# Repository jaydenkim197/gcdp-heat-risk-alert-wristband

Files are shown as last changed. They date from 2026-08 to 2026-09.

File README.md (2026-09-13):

# GCDP Heat Risk Alert Wristband

Wearable safety-alert prototype developed for the 2025-2 Global CDP
Thailand-Korea program. The device measures pulse and skin temperature,
acquires GNSS coordinates, and sends an emergency SMS over LTE-M.

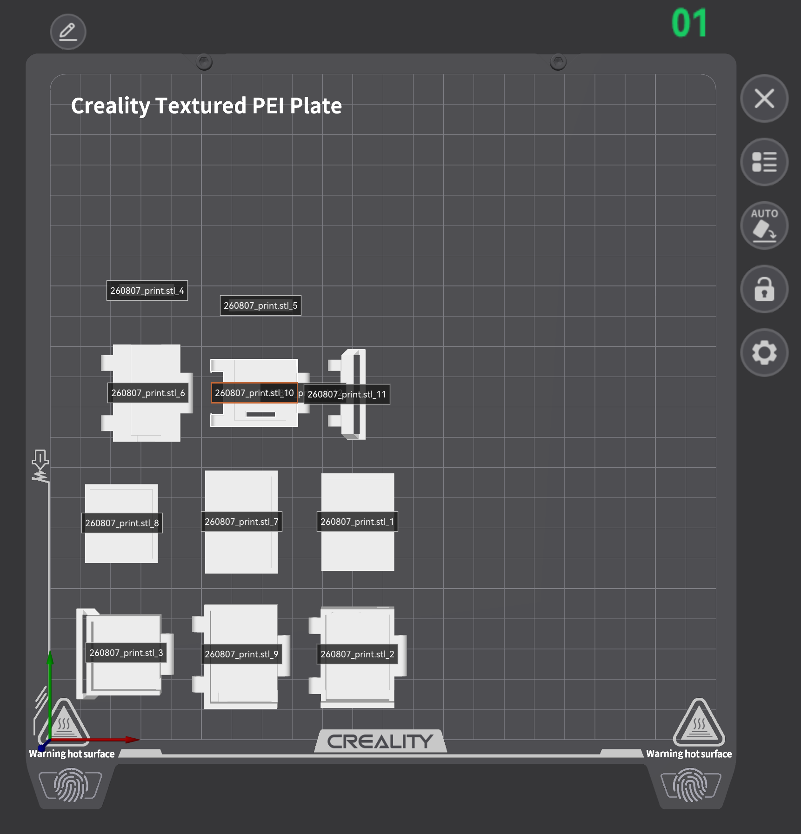
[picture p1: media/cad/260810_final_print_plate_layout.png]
Final modular housing print layout


Latest housing revision prepared for printing on 2026-08-10.

## Prototype Hardware

- ESP32-C3 SuperMini controller
- M5Stack Stamp CatM S003 (SIM7080G) LTE-M/NB-IoT modem
- Beitian BE-220 GNSS module
- MAX30102 pulse/PPG sensor
- TMP117 temperature sensor
- 3 V active buzzer
- 3.7 V 220 mAh Li-Po battery
- Modular 3D-printed hinged housings

## Verified Prototype Functions

- Concurrent MAX30102 and TMP117 acquisition over I2C
- LTE network registration with an activated SKT-network SIM
- GNSS coordinate acquisition
- SMS transmission containing heart rate, temperature, and location
- Battery-powered operation of the integrated prototype
- Standalone buzzer-guided measurement workflow

## ESP32-C3 SuperMini Pin Map

| Function | GPIO |
| --- | ---: |
| I2C SDA (MAX30102/TMP117) | 8 |
| I2C SCL (MAX30102/TMP117) | 9 |
| Stamp CatM RX into ESP | 20 |
| Stamp CatM TX from ESP | 21 |
| BE-220 RX into ESP | 6 |
| BE-220 TX from ESP | 7 |
| Active buzzer | 10 |
| Test trigger | 4 |
| Battery-test input | 5 |

UART labels above are from the ESP32 perspective. Cross the physical UART
connections: module TX to ESP RX, and module RX to ESP TX. All modules must
share ground.

## Repository Layout

- `firmware/`: PlatformIO firmware and captured sensor/UART evidence
- `hardware/pcb/`: Altium schematic and PCB design history
- `hardware/enclosure/`: Fusion export, STEP/STL files, generators, and fit notes
- `docs/`: dated bring-up, integration, power, and module-selection records
- `media/cad/`: selected enclosure renders for quick review
- `evidence/`: dated hardware, 3D-printing, demo, screenshot, and 3D-scan records

For a chronological review of the engineering work, start with
[`evidence/README.md`](evidence/README.md), then read the dated logs in
[`docs/`](docs/). The repository intentionally excludes personal information,
administrative records, raw purchase documents, and generated build caches.

The redacted first-purchase request and supporting quotations are available at
[`docs/260812_GCDP_team5_procurement_request_public.pdf`](docs/260812_GCDP_team5_procurement_request_public.pdf).

Third-party datasheets, downloaded CAD models, raw presentation media,
original procurement files, personal identifiers, and generated build caches
are not tracked in this repository.

## Build and Upload

Open `firmware/` as a PlatformIO project, then run:

```powershell
pio run -e esp32c3_supermini
pio run -e esp32c3_supermini -t upload
pio device monitor -b 115200
```

Before field use, replace the placeholder `STANDALONE_ALERT_NUMBER` in
`firmware/include/pins.h` with the intended recipient number.

## Status

This repository documents a functional presentation prototype. It is not a
certified medical device, and measured values must not be used for diagnosis
or treatment decisions.

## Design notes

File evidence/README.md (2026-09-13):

# Development Evidence

This directory preserves the project evidence that complements the dated
engineering logs in [`../docs/`](../docs/).

## Contents

- `hardware-experiments/`: bench setup photos, early sensor/LTE experiments,
  and enclosure-reference images.
- `3d-printing/`: print-quality evidence, printer and filament settings, and
  the leveling-test STL used during prototype fabrication.
- `demo/`: final outdoor prototype demonstration video.
- `process-screenshots/`: chronological screenshots from the CAD, slicing, and
  prototype assembly process, plus date-level contact sheets.
- `3d-scan/`: final prototype 3D scan for geometry review.

## Related Engineering Logs

- `../docs/260708_hardware_bringup_log.md`: MCU and I2C sensor bring-up.
- `../docs/260709_lte_sms_integrated_firmware_log.md`: LTE, GNSS, SMS, and
  power/UART recovery tests.
- `../docs/260713_battery_standalone_alert_test_log.md`: battery-powered
  standalone alert-flow test.
- `../docs/260731_stamp_catm_bringup_diagnostic.md`: Stamp CatM diagnostic
  measurements and UART validation.
- `../docs/260801_BE-220_bringup_and_fix_log.md`: external GNSS baud-rate
  diagnosis and outdoor-fix validation.

## Scope Note

The artifacts document a functional educational prototype, not a certified
medical device. Third-party datasheets, downloaded reference models, purchase
records, and personal identifiers are intentionally excluded from this public
repository.

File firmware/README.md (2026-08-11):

# Heat Risk Alert Wristband Firmware

Initial PlatformIO firmware workspace for the GCDP Korea prototype.

## Hardware Context

Target device:
- ESP32 main controller
- MAX30102 PPG sensor on I2C
- TMP117 temperature sensor on I2C
- SIM7080G LTE/GNSS module on UART
- Active buzzer on GPIO
- Li-Po battery with TP4056 charging and power regulation

## First Bring-Up Order

1. Build and upload the `esp32dev` environment first.
2. Open the serial monitor at `115200`.
3. Confirm the buzzer chirps once on boot.
4. Confirm I2C scan sees:
   - `0x48` for TMP117
   - `0x57` for MAX30102
5. Confirm the LTE module responds to `AT`.
6. Only after these pass, move to SMS/GPS and state-machine integration.

## Common Commands

From this directory:

```powershell
$pio = "$env:APPDATA\Python\Python311\Scripts\pio.exe"
& $pio run -e esp32dev
& $pio run -e esp32dev -t upload
& $pio device monitor -b 115200
```

Other configured environments:

```powershell
& $pio run -e xiao_esp32c3
& $pio run -e esp32c3_supermini
```

## Default Pin Map

ESP32 DevKitC:

| Function | GPIO |
| --- | ---: |
| I2C SDA | 21 |
| I2C SCL | 22 |
| LTE RX | 16 |
| LTE TX | 17 |
| Buzzer | 25 |

Seeed XIAO ESP32-C3:

| Function | GPIO |
| --- | ---: |
| I2C SDA | 6 |
| I2C SCL | 7 |
| LTE RX | 20 |
| LTE TX | 21 |
| Buzzer | 10 |

ESP32-C3 SuperMini defaults are provisional. Verify against the exact board pinout before wiring.

## Notes

- LTE modules can draw short current spikes above 1 A. Use a stable supply and place bulk capacitance close to the LTE module power input.
- Keep ESP32 and SIM7080G UART grounds common.
- For SIM7080G UART, connect ESP32 TX to module RX and ESP32 RX to module TX.
- The first firmware is intentionally a bring-up sketch, not the final emergency algorithm.

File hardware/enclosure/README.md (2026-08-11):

# GCDP Wristband Case Modeling

Updated: 2026-07-25

Purpose: Fusion workspace for the wearable prototype case/blockout.

## Current Modeling Goal

Create a practical blockout first, not a polished final enclosure.

The prototype will likely be:

- wired modules
- fixed inside a TPU/printed holder
- covered or enclosed enough for wearable presentation
- supported by a presentation-only PCB design image later

## Folder Map

- `fusion`: Fusion source/exported archive files.
- `exports`: STL/STEP/3MF outputs.
- `references`: reference images imported into Fusion or used for modeling.
- `measurements`: measurement tables and photos.
- `renders`: screenshots/renders for reports and presentation.

## Fixed Modules

- ESP32-C3 SuperMini
- M5Stack Stamp CatM S003
- Beitian BE-220 GPS/GNSS
- TMP117 breakout
- MAX30102 breakout
- 3 V active buzzer
- TW-602035 3.7 V 380 mAh Li-Po battery

## Blockout Priority

1. Skin-facing sensor region: MAX30102 optical window and TMP117 contact zone.
2. Top/outward GPS region: BE-220 patch antenna faces outward/upward.
3. LTE region: Stamp CatM and LTE antenna kept away from GPS patch and skin side where possible.
4. Battery protection: avoid sharp compression and provide retention.
5. Debug access: ESP32-C3 USB-C remains reachable.
6. Wire strain relief: every module wire exit needs room.

## First Fusion Components

Create one component per object:

- `WRIST_REFERENCE`
- `CASE_BASE`
- `CASE_LID`
- `ESP32_C3_SUPERMINI_BLOCK`
- `STAMP_CATM_BLOCK`
- `BE220_GPS_BLOCK`
- `BATTERY_BLOCK`
- `MAX30102_BLOCK`
- `TMP117_BLOCK`
- `BUZZER_BLOCK`
- `BUTTON_BLOCK`
- `WIRE_CHANNELS`

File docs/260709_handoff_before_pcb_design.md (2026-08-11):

# 회로 설계 인수인계서

Date: 2026-07-09

Project: GCDP Heat Risk Alert Wristband

Purpose: 회로 설계 채팅으로 넘어가기 전, 지금까지 직접 실험한 사실, 검증 결과, 판단 근거, 확정 결정, 미해결 리스크를 끊기지 않게 전달한다.

## 0. 최종 요약

1차 PCB는 완제품형 칩 통합 PCB가 아니라, 검증된 모듈들을 얹는 carrier board 성격으로 진행한다.

최종 결정:

```text
MCU: ESP32-C3 SuperMini 모듈을 1차 PCB에 그대로 얹는다.
MCU 칩 단위 통합: 1차 PCB에서는 하지 않는다.
GPS/GNSS: 반드시 넣는다.
통신 모듈: 1차 PCB에 통합한다. 기존 대형 devkit은 최종 형상에 부적합하므로 기능 검증용으로만 본다.
배터리: Li-Po 사용.
충전회로: 1차 PCB에는 넣지 않는다.
```

현재까지 보드 기반 기능 검증은 1차 완료로 본다. 남은 핵심 작업은 기능 검증이 아니라 회로 설계 결정이다.

가장 중요한 설계 쟁점:

```text
1. GNSS 포함 통신 모듈 선정
2. SIM7080G 전원 레일 설계
3. Li-Po에서 MCU와 통신 모듈에 어떤 전압을 공급할지 결정
4. SIM7080G PWRKEY/PWRK 회로를 devkit 기준이 아니라 최종 모듈 reference circuit 기준으로 설계
5. MAX30102/TMP117의 실제 착용 구조 반영
```

## 1. 작업 공간 정책

작업 공간 정책은 다음과 같이 확정했다.

```text
N: 드라이브 / NAVER MYBOX cloud
-> 문서, 로그, 설계 메모 보관

C:\Users\sukhe\Desktop\GCDP_codex_temp
-> 임시 개발, PlatformIO build, firmware, capture, 기타 실험 작업
```

활성 펌웨어 작업 경로:

```text
C:\Users\sukhe\Desktop\GCDP_codex_temp\firmware
```

문서/로그 경로:

```text
N:\Own\01_YU\프로젝트 및 활동\2025-2_GCDP(Thailand-Korea)\GCDP_하계(Korea)\project
```

기존에 N 드라이브 쪽에 생겼던 `project\firmware`는 cloud sync와 build/cache 문제를 피하기 위해 삭제했다. 프로젝트 완료 전까지 N 드라이브에는 문서/기록만 둔다.

## 2. 기존 문서와 로그

기존 로그:

```text
N:\Own\01_YU\프로젝트 및 활동\2025-2_GCDP(Thailand-Korea)\GCDP_하계(Korea)\project\logs\2026-07-08_hardware_bringup_log.md
N:\Own\01_YU\프로젝트 및 활동\2025-2_GCDP(Thailand-Korea)\GCDP_하계(Korea)\project\logs\2026-07-09_lte_sms_integrated_firmware_log.md
```

회로 설계 전 메모:

```text
N:\Own\01_YU\프로젝트 및 활동\2025-2_GCDP(Thailand-Korea)\GCDP_하계(Korea)\project\design\pre_pcb_circuit_notes.md
```

본 인수인계서:

```text
N:\Own\01_YU\프로젝트 및 활동\2025-2_GCDP(Thailand-Korea)\GCDP_하계(Korea)\project\design\handoff_before_pcb_design_2026-07-09.md
```

## 3. 개발 환경

PlatformIO 기반으로 진행했다.

설치/사용 확인:

```text
PlatformIO Core
VS Code PlatformIO IDE extension
VS Code C/C++ extension
Espressif32 PlatformIO platform
ESP32 / ESP32-C3 toolchains
```

PlatformIO 환경:

```text
esp32dev
xiao_esp32c3
esp32c3_supermini
```

현재 `platformio.ini`에는 다음 env가 존재한다.

```ini
[env:xiao_esp32c3]
board = seeed_xiao_esp32c3
build_flags =
  -D I2C_SDA_PIN=6
  -D I2C_SCL_PIN=7
  -D LTE_RX_PIN=20
  -D LTE_TX_PIN=21
  -D BUZZER_PIN=10
  -D LTE_PWRK_PIN=5

[env:esp32c3_supermini]
board = esp32-c3-devkitm-1
build_flags =
  -D I2C_SDA_PIN=8
  -D I2C_SCL_PIN=9
  -D LTE_RX_PIN=20
  -D LTE_TX_PIN=21
  -D BUZZER_PIN=10
  -D LTE_PWRK_PIN=5
```

주의:

- 대화 중 XIAO ESP32-C3와 ESP32-C3 SuperMini 비교가 있었다.
- 최종 1차 PCB 결정은 `ESP32-C3 SuperMini 모듈 탑재`이다.
- 펌웨어에는 XIAO와 SuperMini env가 둘 다 들어 있다.
- 회로 설계 채팅에서는 SuperMini 실제 핀맵 기준으로 다시 고정해야 한다.

## 4. MCU 관련 판단

### 4.1 MCU 칩 단위 통합을 하지 않는 이유

1차 PCB에서 MCU를 ESP32-C3 칩 단위로 직접 넣지 않기로 결정했다.

판단 근거:

- ESP32-C3 칩 단위 설계는 USB 회로, EN/BOOT 회로, 3.3 V regulator, crystal/flash/antenna/RF layout, 업로드/디버깅 회로까지 고려해야 한다.
- RF/안테나 layout과 인증/간섭 이슈가 커진다.
- 현재 프로젝트 단계에서는 기능 검증과 1차 착용형 prototype이 우선이다.
- 일정과 디버깅 난이도를 고려하면 MCU 모듈을 carrier PCB에 얹는 것이 현실적이다.

결정:

```text
1차 PCB: ESP32-C3 SuperMini 모듈을 그대로 얹는다.
2차 이후: 필요하면 ESP32-C3 module/chip integration 검토.
```

### 4.2 SuperMini vs XIAO 판단

XIAO ESP32-C3로 바꾸는 데 펌웨어 시간은 크지 않다. 같은 ESP32-C3 계열이고 PlatformIO env도 이미 있다.

하지만 최종 판단:

```text
지금은 SuperMini 유지.
```

판단 근거:

- 현재 주요 병목은 MCU가 아니라 통신 모듈, GPS/GNSS, 전원부다.
- SuperMini는 작고 1차 PCB 크기 감각에 더 가깝다.
- 이미 ESP32-C3 계열에서 센서/부저/LTE 통신 검증이 진행되었다.
- XIAO로 바꾸면 큰 기능 이득보다 핀맵/배선 재확인 비용이 생긴다.

## 5. 센서 검증 결과

### 5.1 TMP117 온도 센서

사용 핀:

```text
VIN
GND
SCL
SDA
INT
ADDR
```

실제 사용:

```text
VIN -> 3V3
GND -> GND
SDA -> I2C SDA
SCL -> I2C SCL
INT -> 미사용
ADDR -> 미사용
```

I2C address:

```text
0x48
```

검증 결과:

- I2C scan에서 `0x48` 감지.
- 온도 읽기 성공.
- 예시 측정값:

```text
32.84 C
33.01 C
33.12 C
33.21 C
```

통합 firmware에서는 TMP117 값이 비정상 범위를 벗어나면 reject하도록 했다.

현재 적용한 sanity range:

```text
-40 C to 125 C
```

설계 주의:

- 피부온도를 의미 있게 보려면 회로보다 기구적 열접촉 구조가 중요하다.
- PCB 위에만 올리면 주변 온도/보드 열 영향을 받을 수 있다.
- 최종 착용 구조에서 TMP117 위치를 피부 쪽에 가깝게 배치해야 한다.

### 5.2 MAX30102 심박/착용 감지 센서

사용 핀 라벨:

```text
GND
D
IRO
INT
VIN
SDA
SCL
GND
```

실제 사용:

```text
VIN -> 3V3
GND -> GND
SDA -> I2C SDA
SCL -> I2C SCL
INT/IRO/D -> 미사용
```

I2C address:

```text
0x57
```

Part ID:

```text
0x15
```

검증 결과:

- I2C scan에서 `0x57` 감지.
- RED/IR raw data 읽기 성공.
- 손가락 올린 상태에서 RED/IR 값 증가 확인.
- 예시 값:

```text
red = 104552
ir  = 130099
```

연속 sampling 예시:

```text
Sample rate: about 49.98 Hz
RED range: 107248 to 107786
IR range: 133719 to 134472
```

초기 BPM 추정:

```text
Mean BPM: 115.2
Median BPM: 115.4
```

해석:

- BPM 추정은 waveform 검증용 crude peak detector였다.
- 최종 심박 알고리즘으로 확정한 것이 아니다.
- 현재 중요한 검증은 optical sensor가 살아 있고 RED/IR waveform이 나온다는 점이다.

착용 감지:

```text
wear on threshold  = 80000
wear off threshold = 60000
confirmation count = 3
```

사용자 확인:

- 손가락/접촉 감지 시 부저 반응.
- delay는 약 1~2초 내외로 느껴졌고 현재 prototype 단계에서는 만족.

설계 주의:

- MAX30102는 회로보다 물리 배치가 중요하다.
- 피부 밀착, 차광, 압력, 센서 창 높이, 주변광 차단을 고려해야 한다.
- PCB에 고정할지, 별도 작은 sensor board로 빼서 피부 접촉부에 둘지 설계 단계에서 결정해야 한다.

### 5.3 TMP117 + MAX30102 동시 I2C 검증

두 센서는 같은 I2C bus에서 동시에 동작했다.

동시 scan 결과:

```text
0x48 TMP117
0x57 MAX30102
```

결론:

```text
TMP117과 MAX30102는 하나의 I2C bus에 같이 연결 가능.
```

회로 설계 주의:

- pull-up 저항 값을 최종 PCB에서 정해야 한다.
- breakout module에 이미 pull-up이 있는 경우 prototype에서는 중복 pull-up이 있을 수 있다.
- 1차 PCB에서 센서를 직접 실장한다면 SDA/SCL에 3.3 V pull-up을 명확히 넣어야 한다.

## 6. 부저 검증 결과

부저 연결:

```text
ESP32-C3 GPIO10 -> buzzer signal
GND -> GND
```

검증 결과:

- GPIO10으로 부저 ON/OFF 확인.
- 착용 감지와 연동해 접촉 시 부저 ON, 제거 시 OFF 테스트 완료.
- 사용자 체감 delay는 prototype 단계에서 만족.

회로 설계 주의:

- active buzzer가 저전류이면 GPIO 직접 구동 가능할 수 있다.
- 부저 전류가 GPIO safe limit을 넘으면 transistor driver를 넣어야 한다.
- wearable 용도이므로 소리 크기/소비전류/사용자 불편감을 같이 고려해야 한다.

## 7. 통신 모듈 실험 결과

### 7.1 작은 SIM7080G 6핀 모듈

핀 라벨:

```text
5V
3V3
GND
Rf
Tx
Rx
```

실험:

- 5V, GND, TX/RX를 ESP32-C3 UART에 연결.
- TX/RX direction 바꿔봄.
- 여러 baud scan.

결과:

```text
LED는 켜졌으나 AT 응답 없음.
```

가능 원인:

- 별도 power key 필요.
- UART가 비활성.
- 전원 조건 문제.
- 보드 내부 동작 조건 불명.

결론:

```text
해당 작은 6핀 모듈은 bring-up 실패. 최종 설계 근거로 사용하지 않는다.
```

### 7.2 SIM7080G developer kit

핀 라벨:

```text
DTR
GND
VDD
PWRK
UTX
URX
GND
```

추가 구성:

- micro USB connector
- 4-pin connector
- 3개 antenna connector

PCB marking:

```text
CAT-1-A76-80X
NB-SIM-7080
SIM-800/868
```

초기 USB test:

- micro USB 연결 시 LED는 켜졌지만 Windows COM port는 새로 잡히지 않았다.
- cable이 power-only일 가능성 또는 USB-UART 미노출 가능성이 있었다.

ESP32-C3 UART 경유 test:

동작한 UART:

```text
SIM7080G DevKit UTX -> ESP32-C3 GPIO20 or GPIO21 실험 중 최종 firmware는 LTE_RX_PIN=20 사용
SIM7080G DevKit URX -> ESP32-C3 GPIO21 or GPIO20 실험 중 최종 firmware는 LTE_TX_PIN=21 사용
GND common
baud = 115200
```

주의:

- 초기 로그에는 배선 방향을 바꿔가며 찾은 흔적이 있다.
- 최종 통합 firmware 기준은 `LTE_RX_PIN=20`, `LTE_TX_PIN=21`.
- 회로 설계 시에는 최종 채택 통신 모듈 datasheet의 TX/RX naming 기준으로 다시 교차 연결해야 한다.

AT 성공:

```text
AT -> OK
ATI -> R1951.07 / OK
AT+CPIN? -> +CPIN: READY
```

## 8. SIM / SKT / SMS 검증

SIM:

- 물리 SIM을 SKT망으로 개통 후 사용.
- SIM 전화번호 및 수신 테스트 전화번호는 대화에 존재하지만 문서에는 개인정보 보호를 위해 그대로 적지 않는다.

SKT network:

성공 PLMN:

```text
45005
```

실패한 PLMN:

```text
45012 -> no network service
```

안테나 전:

```text
AT+CSQ -> 99,99
AT+CEREG? -> 0,2
```

안테나 후:

```text
AT+CSQ -> 23 to 26,99
AT+CEREG? -> registered
AT+COPS? -> 45005 or SKTelecom
AT+CGATT? -> 1
```

Cat-M mode:

```text
AT+CMNB=1
AT+CNMP? -> +CNMP: 38
AT+CBAND? -> ALL_MODE
```

SMS:

실제 SMS 전송 성공.

테스트 메시지:

```text
GCDP SIM7080G SMS TEST
```

사용자 확인:

```text
문자 수신 성공.
```

중요 안전 이슈:

- 초기 test firmware에서 one-shot flag가 RAM에만 있어서 reset/re-upload 후 같은 SMS가 다시 발송되었다.
- 사용자가 SMS 500건 한도를 우려했다.
- 이후 automatic SMS는 모두 막았다.

현재 정책:

```text
SMS는 수동 serial command로만 전송.
부팅, reset, LTE registration, state change만으로는 SMS 전송 금지.
```

현재 SMS 명령:

```text
SMS <number> <message>
```

회로 설계와 직접 관련된 결론:

- SIM7080G 계열로 SKT망 registration과 SMS 송신이 실제로 가능함을 확인했다.
- LTE antenna는 필수다.
- 통신 모듈 전원 안정성이 매우 중요하다.

## 9. GNSS/GPS 검증

GPS/GNSS는 프로젝트 최종 요구사항으로 확정했다.

SIM7080G developer kit에서 GNSS command path는 검증되었다.

추가한 firmware command:

```text
GNSS
GNSSOFF
```

관측 sequence:

```text
AT+CGNSPWR=1
OK
AT+CGNSINF
+CGNSINF: 1,,,36.050000,127.330003,-19.819,,,1,,0.1,0.1,0.1,,,,191841.8,6000.0
OK
[gnss] coordinate acquired
```

GNSS off:

```text
AT+CGNSPWR=0
OK
```

해석:

- `+CGNSINF: 1,1` 형태가 아니어도 latitude/longitude field가 유효하면 coordinate acquired로 처리하도록 firmware 수정했다.
- 실내/창가/안테나 조건에 따라 GNSS fix reliability는 추가 확인 필요.
- 최종 PCB에는 LTE antenna와 GNSS antenna를 별도로 고려해야 한다.

중요 부품 판단:

### M5Stack U137 CatM+GNSS Unit

특징:

- SIM7080G 기반.
- Cat-M/NB-IoT + GNSS 지원.
- LTE/GNSS dual SMA antenna.
- MicroSIM.
- 외부 DC 9-24 V 또는 HY2.0 5 V.
- UART 3.3 V TTL.
- GNSS 지원.
- 크기 약 `62 x 40 x 18.4 mm`.

판단:

- 기능적으로는 통신 + GNSS가 모두 들어 있어 prototype 검증에 유리.
- 하지만 wristband 최종/1차 PCB 관점에서는 크다.

### M5Stamp CAT-M Module S003

특징:

- SIM7080G 기반.
- Cat-M/NB-IoT 지원.
- UART 115200 8N1.
- MicroSIM.
- IPEX LTE antenna.
- 5 V 입력.
- 제품 크기 약 `30.1 x 20.1 x 5.5 mm`.
- GNSS 없음.

판단:

- 작고 1차 PCB에 올리기 좋다.
- 그러나 GPS/GNSS가 없다.
- 최종 요구사항이 GPS 필수이므로 S003 단독은 부적합.

최종 GPS 관련 결정:

```text
GPS/GNSS는 반드시 넣는다.
S003 단독 사용은 안 된다.
통신 모듈은 PCB에 통합하되, GNSS 지원 모듈이거나 별도 GNSS 모듈을 추가해야 한다.
```

회로 설계 채팅에서 가장 먼저 정해야 할 점:

```text
1. SIM7080G 기반 GNSS 지원 모듈을 PCB에 올릴 것인가?
2. 아니면 S003 같은 작은 Cat-M module + 별도 GNSS module 조합으로 갈 것인가?
```

현재 판단 우선순위:

- 크기만 보면 S003이 매력적.
- 하지만 GPS 필수이므로 S003 단독은 탈락.
- 통신+GNSS 통합 모듈을 찾는 것이 회로 단순성 측면에서 유리하다.
- 크기를 더 줄이려면 Cat-M module과 GNSS module을 분리해야 한다.

## 10. PWRK/PWRKEY 전원 제어 실험

SIM7080G developer kit에서 PWRK 관련 실험을 했다.

초기 관찰:

- PWRK를 GND에 1~2초 연결했다가 떼면 green LED가 깜빡이며 살아난 적이 있다.
- 이후 firmware에서 `MODEMPWR` command를 추가해 ESP32-C3 GPIO5로 PWRK를 LOW pulse하도록 했다.

추가 firmware command:

```text
MODEMPWR [ms]
MODEMOFF
PWRKHIGH [ms]
LTEPROBE
```

`MODEMOFF`:

```text
AT+CPOWD=1
```

결과:

- `AT+CPOWD=1`로 modem power-down은 확인했다.
- power-down 후 AT no response 상태 확인.
- `MODEMPWR` LOW pulse로는 관찰 시간 내 modem이 확실히 다시 살아나는 것을 확인하지 못했다.
- `PWRKHIGH 3000`은 modem이 켜져 있을 때 `NORMAL POWER DOWN`을 유발했다.
- 이후 green LED가 깜빡이는 상태에서는 실제로 modem이 살아 있었고, re-upload/reset 및 UART probe 후 AT 통신이 복구되었다.

중요 해석:

- developer kit의 PWRK 핀은 단순한 active-low button이라고 단정하면 안 된다.
- HIGH pulse가 power-down을 유발하는 상황도 관찰되었다.
- external micro-USB power 또는 보조배터리 전원 공급 후 modem 안정성이 좋아졌다.
- no response 상태가 항상 modem death를 의미하지는 않았다. reset/timing/UART synchronization issue일 수 있다.
- 최종 PCB에서 devkit의 PWRK behavior를 그대로 복사하면 안 된다.

최종 설계 지침:

```text
PWRKEY/PWRK는 최종 선택한 SIM7080G module datasheet/reference circuit 기준으로 설계한다.
developer kit behavior는 참고 기록으로만 본다.
```

예상 회로 원칙:

- MCU GPIO가 PWRKEY를 직접 push-pull로 강하게 drive하지 않도록 한다.
- 일반적으로 open-drain/open-collector style low-side control 또는 reference circuit 권장 방식을 따른다.
- power-on/off timing은 module datasheet timing을 따른다.

## 11. 전원 관련 관찰과 최종 결정

관찰:

- SIM7080G developer kit는 전원 조건에 민감했다.
- antenna 연결 전에는 신호가 사실상 없었다.
- 외부 micro-USB/보조배터리 전원 공급 후 modem 안정성이 좋아졌다.
- 통신 모듈은 MCU 3.3 V에서 직접 공급하면 안 된다.
- LTE attach/SMS/GNSS 시 전류 spike를 고려해야 한다.

최종 결정:

```text
1차 PCB 전원: Li-Po 사용.
1차 PCB 충전회로: 넣지 않는다.
```

이 결정의 의미:

- PCB에 charging IC, USB charging path, power-path management를 넣지 않는다.
- Li-Po는 외부 충전 또는 분리 충전을 전제로 해야 한다.
- 단, 안전을 위해 battery protection이 내장된 Li-Po pack을 쓰는지 확인해야 한다.
- PCB에는 최소한 reverse/overcurrent/전원 switch/fuse/protection 필요 여부를 회로 설계에서 판단해야 한다.

필수 설계 과제:

```text
Li-Po nominal 3.7 V, full 4.2 V, cutoff 약 3.0 V대
ESP32-C3 SuperMini 입력 요구 전압
통신 모듈 입력 요구 전압
SIM7080G peak current
5 V boost converter 필요 여부
3.3 V regulator 필요 여부
bulk capacitor 용량과 배치
```

전원 관련 강한 권고:

- SIM7080G 전원 rail 근처에 bulk capacitor를 둔다.
- LTE module power trace는 짧고 넓게 잡는다.
- MCU와 sensor 3.3 V rail이 modem current spike에 흔들리지 않게 분리/필터링을 고려한다.
- 1차 PCB라도 power test point를 반드시 둔다.

## 12. 현재 통합 펌웨어 상태

파일:

```text
C:\Users\sukhe\Desktop\GCDP_codex_temp\firmware\src\main.cpp
C:\Users\sukhe\Desktop\GCDP_codex_temp\firmware\platformio.ini
C:\Users\sukhe\Desktop\GCDP_codex_temp\firmware\include\pins.h
```

구현된 state:

```text
BOOT
NOT_WORN
NORMAL
SUSPECT
ALARM
EMERGENCY_READY
ERROR
```

상태 의미:

```text
BOOT -> 초기화
NOT_WORN -> 착용/접촉 없음
NORMAL -> 착용 감지, 위험 조건 없음
SUSPECT -> 위험 의심 조건 시작
ALARM -> 위험 조건 지속
EMERGENCY_READY -> 알림 전송 준비 상태
ERROR -> sensor failure 지속
```

현재 주요 parameter:

```text
SENSOR_SAMPLE_MS = 100
TEMP_SAMPLE_MS = 1000
STATUS_PRINT_MS = 1000
LTE_CHECK_MS = 60000
SUSPECT_CONFIRM_MS = 10000
ALARM_COUNTDOWN_MS = 30000
WEAR_ON_IR_THRESHOLD = 80000
WEAR_OFF_IR_THRESHOLD = 60000
WEAR_CONFIRM_COUNT = 3
TEMP_SUSPECT_C = 38.0
```

현재 serial commands:

```text
HELP
STATUS
LTE
LTEPROBE
GNSS
GNSSOFF
MODEMPWR [ms]
PWRKHIGH [ms]
MODEMOFF
ALARM
CANCEL
SMS <number> <message>
```

SMS safety:

```text
Automatic SMS disabled.
Manual command only.
```

센서 안정성 patch:

- TMP117 transient fail이 몇 번 발생해도 즉시 ERROR로 가지 않도록 했다.
- MAX30102 transient fail도 즉시 ERROR로 가지 않도록 했다.
- 짧은 I2C failure에는 last valid reading을 유지한다.
- 지속 failure일 때만 ERROR.

## 13. 1차 PCB에 반영할 기능 블록

1차 PCB block:

```text
Li-Po battery input
Power switch / protection / regulation
ESP32-C3 SuperMini module seat
GNSS-capable Cat-M/NB-IoT communication module or Cat-M + separate GNSS
MicroSIM holder if module does not include one
LTE antenna connector
GNSS antenna connector
TMP117 temperature sensor
MAX30102 optical sensor
Buzzer driver/output
Debug/programming access
Test points
```

1차 PCB에서 하지 않는 것:

```text
ESP32-C3 chip-level integration
charging circuit
fully optimized final wearable miniaturization
RF tuning beyond reasonable module reference layout
```

## 14. 회로 설계에 넘길 확정 결정

확정:

```text
GPS/GNSS 기능은 반드시 포함한다.
1차 PCB에서 MCU는 ESP32-C3 SuperMini 모듈을 그대로 얹는다.
1차 PCB에서 MCU 칩 단위 통합은 하지 않는다.
통신 모듈은 PCB에 통합한다.
기존 SIM7080G developer kit는 기능 검증용이며 최종 1차 PCB 탑재 대상이 아니다.
Li-Po battery를 사용한다.
1차 PCB에는 충전회로를 넣지 않는다.
SMS는 자동 발송하지 않는다. 자동 emergency workflow는 별도 구현 전까지 막아둔다.
TMP117과 MAX30102는 같은 I2C bus에 연결 가능하다.
부저는 GPIO로 제어 가능함을 확인했다.
LTE/SMS/GNSS는 SIM7080G 계열에서 실제 동작 확인했다.
```

미확정:

```text
최종 GNSS 포함 통신 모듈 part number
Cat-M+GNSS 통합 모듈 vs Cat-M 모듈 + 별도 GNSS 모듈
SIM holder를 module 내장으로 쓸지 PCB에 둘지
LTE antenna connector type
GNSS antenna connector type
Li-Po 전압을 어떤 rail로 변환할지
5 V boost 필요 여부
3.3 V regulator 구성
PWRKEY/PWRK 회로
MAX30102/TMP117 물리 배치
부저 driver 필요 여부
배터리 protection/fuse/switch 방식
```

## 15. 회로 설계 시작 순서 권장

다음 채팅에서 회로 설계를 시작할 때는 이 순서가 좋다.

```text
1. 최종 통신/GNSS 모듈 선정
2. 해당 module datasheet/reference circuit 확보
3. module 전원 요구사항 확인
4. Li-Po -> required rails power tree 작성
5. ESP32-C3 SuperMini carrier pin map 확정
6. I2C sensor bus 확정
7. LTE/GNSS antenna connector and placement 결정
8. SIM holder/module 내장 여부 결정
9. buzzer driver 여부 결정
10. test point/debug connector 추가
11. schematic 작성
12. ERC/DFM 검토
```

가장 먼저 볼 것:

```text
GPS 필수이므로 S003 단독은 탈락.
통신+GNSS를 통합한 작은 module을 찾거나, S003급 Cat-M module + small GNSS module 조합으로 간다.
```

## 16. 다음 채팅에 반드시 전달해야 하는 경고

1. `PWRK`는 devkit에서 이상하게 동작했다. 최종 PCB는 devkit wiring을 베끼지 말고 최종 module datasheet를 따라야 한다.

2. `S003 M5Stamp CAT-M`은 작지만 GNSS가 없다. GPS 필수 조건과 충돌한다.

3. `U137 CatM+GNSS Unit`은 GNSS가 있지만 크다. 1차 PCB에 그대로 쓰기보다는 기능 reference로 보는 편이 낫다.

4. SIM7080G 계열은 전원 안정성이 중요하다. 보조배터리/외부전원 연결 후 안정성이 개선된 경험이 있다.

5. SMS 자동 발송은 조심해야 한다. reset/re-upload로 중복 문자 발송된 경험이 있으므로 rate limit과 persistent sent flag 없이는 자동 SMS를 켜면 안 된다.

6. MAX30102는 회로보다 기구/착용 구조가 성능에 큰 영향을 준다.

7. TMP117도 피부온도 측정 목적이면 기구적 열접촉 설계가 필요하다.

8. N drive에는 firmware/build를 두지 않는다. 문서와 기록만 둔다.

## 17. 현재 판단의 한 문장 버전

```text
센서, 부저, LTE, SMS, GNSS의 기능 검증은 끝났고, 1차 PCB는 ESP32-C3 SuperMini를 얹는 carrier board로 가며, GPS는 필수이므로 GNSS 포함 통신 모듈 또는 별도 GNSS 모듈을 선정한 뒤 Li-Po 기반 전원부와 SIM7080G reference 회로를 중심으로 schematic을 시작해야 한다.
```

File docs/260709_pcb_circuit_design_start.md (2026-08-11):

# GCDP Heat Risk Alert Wristband - 1st PCB Circuit Design Start

Date: 2026-07-09

Scope: 1차 PCB 회로 설계 시작 문서. 인수인계서, 기존 bring-up 로그, pre-PCB 회로 메모를 기준으로 누락 결정사항을 점검하고, 블록 다이어그램, 부품 후보, 전원 구조, ESP32-C3 SuperMini carrier pin map, schematic 작성 순서를 정리한다.

## 1. 설계 기준 요약

확정 기준:

- 1차 PCB는 완제품형 칩 통합 PCB가 아니라 검증된 모듈을 얹는 carrier board로 설계한다.
- MCU는 ESP32-C3 SuperMini 모듈을 그대로 탑재한다.
- MCU 칩 단위 통합은 1차 PCB에서 하지 않는다.
- GPS/GNSS는 반드시 포함한다.
- 통신 모듈은 PCB에 통합한다. 기존 SIM7080G developer kit는 최종 탑재 대상이 아니다.
- Li-Po 배터리를 사용한다.
- 1차 PCB에는 충전회로를 넣지 않는다.
- SMS 자동 발송은 계속 금지한다. 현재 정책은 manual serial command only.

검증 완료 기반:

- TMP117, MAX30102, I2C 동시 동작, buzzer GPIO, SIM7080G UART AT, SKT 등록, SMS 송신, SIM7080G GNSS 좌표 수신 확인 완료.
- 통신 모듈 전원 안정성과 antenna 연결은 1차 PCB 설계 핵심 리스크다.

## 2. 누락된 설계 결정사항 점검

| 항목 | 현재 판단 | 1차 PCB 결정 |
| --- | --- | --- |
| 통신/GNSS 모듈 | SIM7080G 계열에서 실제 SKT/SMS/GNSS 검증됨 | 1차 권장: SIM7080G bare SMT module |
| 통합형 vs 분리형 GNSS | 분리형은 부품/펌웨어/antenna가 늘어남 | 통신+GNSS 통합 모듈 우선 |
| SIM holder | bare SIM7080G는 외부 SIM socket 필요 | PCB에 nano/micro SIM holder 배치 |
| LTE antenna connector | developer kit에서 antenna 없이는 사실상 수신 불가 | u.FL/IPEX 계열 우선, 50 ohm RF + PI matching reserve |
| GNSS antenna connector | GNSS 필수, LTE와 별도 고려 필요 | u.FL/IPEX 계열 우선, active/passive 선택 전원 옵션 reserve |
| Li-Po 전원 rail | SIM7080G VBAT 범위가 Li-Po 직접 연결 가능 범위와 겹침 | Li-Po -> protected/switched VBAT_MODEM 직접 공급안 우선 |
| 3.3 V rail | SuperMini/센서용 안정 rail 필요 | Li-Po -> 3.3 V regulator, modem rail과 분리 |
| 5 V boost | SIM7080G bare module에는 필수 아님 | 기본 미사용. SuperMini 5V pin 사용 여부는 조립 옵션으로만 |
| PWRKEY | devkit 동작 복사 금지 | SIM7080G datasheet 기준, open-drain low-side pull-down |
| UART level | SIM7080G UART는 1.8 V domain | ESP32-C3 3.3 V UART와 level shifter 필요 |
| Buzzer driver | buzzer 전류 미확정 | transistor low-side driver 기본 적용 |
| Sensor placement | 회로보다 기구 영향 큼 | MAX30102/TMP117은 skin-side edge/별도 sensor island 고려 |
| Debug/test | PCB bring-up 필수 | UART, I2C, 3V3, VBAT_MODEM, PWRKEY, STATUS, RF option test points |

## 3. 통신/GNSS 모듈 후보

### 3.1 1차 권장: SIMCom SIM7080G bare SMT module

선정 이유:

- 이미 SIM7080G 계열 developer kit로 SKT 등록, SMS 송신, GNSS 좌표 수신을 확인했다.
- SIMCom 공식 제품 정보 기준 SIM7080G는 CAT-M/NB-IoT SMT 모듈이며 GNSS 옵션을 제공한다.
- 크기는 약 17.6 mm x 15.7 mm x 2.3 mm로 1차 wristband carrier PCB에 현실적인 편이다.
- 공급 전압 범위는 2.7 V to 4.8 V라 1-cell Li-Po 전압 범위와 직접 연결 가능하다.
- hardware design 문서 기준 CAT-M/NB-IoT emission peak current는 0.5 A 수준을 고려해야 한다.

주의:

- SIM7080G UART/GPIO는 1.8 V domain이다. ESP32-C3 3.3 V와 직접 연결하지 말고 level shifter 또는 reference transistor circuit을 넣는다.
- SIM card는 1.8 V SIM만 지원한다고 문서에 명시되어 있으므로 SIM holder/USIM 호환성을 확인한다.
- PWRKEY는 내부 1.8 V pull-up이 있으며, 1초 이상 low pulse로 power-on, 1.2초 이상 low pulse로 power-off한다. 상시 GND short 금지.
- RF_ANT와 GNSS_ANT가 별도 pad로 존재하므로 LTE/GNSS antenna connector를 분리한다.

### 3.2 대안 A: Quectel BG77/BG770A-GL 계열

장점:

- SIM7080G보다 더 작은 초소형 LPWA + GNSS 계열로 wristband 최종형에는 매력적이다.
- LTE Cat M1/NB-IoT와 GNSS 통합 방향성은 프로젝트 요구와 맞다.

리스크:

- 현재 firmware, AT command path, SKT/SMS/GNSS 검증은 SIM7080G 기준이다.
- 1차 PCB에서 모듈을 바꾸면 bring-up 리스크가 커진다.
- SIM/PWRKEY/PON_TRIG/power sequencing이 SIM7080G와 다르므로 reference circuit 재검토가 필요하다.

### 3.3 대안 B: M5Stamp CAT-M S003 + 별도 GNSS

판단:

- S003은 작지만 GNSS가 없어 단독 사용 불가다.
- 별도 GNSS 모듈을 추가하면 antenna, UART/I2C, 전원, firmware integration이 늘어난다.
- 1차 PCB 회로 단순성 관점에서는 권장하지 않는다.

결론:

```text
1차 PCB schematic 초안은 SIM7080G bare SMT module 기준으로 시작한다.
BG77/BG770A 계열은 2차 소형화 후보로 남긴다.
```

## 4. 1차 PCB 블록 다이어그램

```mermaid
flowchart LR
  BAT["Protected 1S Li-Po pack<br/>JST or solder pads"] --> SW["Power switch<br/>fuse / reverse protection option"]
  SW --> VBAT["VBAT_MODEM<br/>2.7-4.8 V high-current rail"]
  SW --> REG33["3.3 V regulator<br/>MCU + sensors"]

  VBAT --> MODEM["SIM7080G SMT module<br/>Cat-M/NB-IoT + GNSS"]
  REG33 --> MCU["ESP32-C3 SuperMini module"]
  REG33 --> TMP["TMP117<br/>skin temperature"]
  REG33 --> MAX["MAX30102<br/>optical / wear detection"]
  REG33 --> BUZDRV["Buzzer driver"]

  MCU -- "I2C GPIO8/9" --> TMP
  MCU -- "I2C GPIO8/9" --> MAX
  MCU -- "UART GPIO20/21 via 3.3V-1.8V level shift" --> MODEM
  MCU -- "GPIO5 open-drain control" --> MODEM
  MCU -- "GPIO10" --> BUZDRV
  BUZDRV --> BUZ["Active buzzer"]

  MODEM --> SIM["1.8 V SIM holder<br/>ESD + 100 nF near socket"]
  MODEM --> LTEANT["LTE u.FL/IPEX<br/>50 ohm + PI matching"]
  MODEM --> GNSSANT["GNSS u.FL/IPEX<br/>active/passive option"]
  MCU --> DBG["Debug/test header<br/>UART/USB pads/I2C/power"]
```

## 5. 전원 구조 초안

### 5.1 권장 power tree

```text
Protected 1S Li-Po pack
  -> main power switch / removable jumper
  -> VBAT_RAW
      -> VBAT_MODEM: SIM7080G VBAT pins, short/wide trace, bulk caps near module
      -> 3V3_REG: ESP32-C3 SuperMini 3V3 pin, TMP117, MAX30102, buzzer logic
```

### 5.2 SIM7080G VBAT rail

설계값:

- Nominal: 3.7 V Li-Po
- Full: 4.2 V
- SIM7080G allowed: 2.7 V to 4.8 V
- Peak design current: at least 0.5 A, margin 포함해서 regulator/protection/trace는 1 A급 이상으로 설계

회로:

- VBAT pins 34/35는 반드시 함께 연결한다.
- VBAT_MODEM trace는 짧고 넓게. 1차 PCB에서는 최소 1 mm 이상, 가능하면 2 mm급 polygon/plane 사용.
- 모듈 VBAT pin 근처에 bulk + MLCC를 배치한다.
- 초기 schematic capacitor reserve:
  - 100 uF low-ESR bulk x 2 or x 3 near SIM7080G VBAT
  - 10 uF
  - 1 uF
  - 100 nF
  - TVS diode near VBAT pins
- 정상 동작 중 VBAT를 강제로 끊는 설계는 피한다. power-off는 AT+CPOWD=1 또는 PWRKEY 절차를 우선한다.

### 5.3 3.3 V rail

용도:

- ESP32-C3 SuperMini 3V3 input
- TMP117
- MAX30102
- buzzer driver input side
- level shifter MCU side

요구:

- modem current spike가 3.3 V rail에 직접 흔들림을 주지 않게 VBAT_MODEM과 decoupling/return path를 분리한다.
- SuperMini의 5V pin으로 공급할지 3V3 pin으로 공급할지는 모듈 상세 회로 확인 후 freeze한다. 1차 schematic에는 3V3 regulated input을 기본으로 잡고, 필요시 5V boost option footprint를 DNP로 남긴다.

### 5.4 배터리/보호

1차 PCB에는 충전회로를 넣지 않는다.

필수 조건:

- protected Li-Po pack 사용을 BOM/조립 지시서에 명시한다.
- PCB 입력단에 power switch 또는 removable jumper를 둔다.
- fuse/polyfuse 또는 0 ohm shunt footprint를 둬 bring-up 시 current measurement 가능하게 한다.
- reverse protection은 connector 실수 가능성이 있으면 ideal diode/load switch 또는 series protection footprint를 둔다.

## 6. ESP32-C3 SuperMini carrier pin map

SuperMini 기준 최종 draft:

| Function | ESP32-C3 SuperMini pin | Net | 비고 |
| --- | --- | --- | --- |
| I2C SDA | GPIO8 | I2C_SDA_3V3 | SuperMini pinout의 SDA. firmware `esp32c3_supermini` env와 일치 |
| I2C SCL | GPIO9 | I2C_SCL_3V3 | SuperMini pinout의 SCL |
| LTE UART RX | GPIO20 | LTE_TXD_TO_MCU_1V8 via level shift | modem TXD -> MCU RX |
| LTE UART TX | GPIO21 | LTE_RXD_FROM_MCU_1V8 via level shift | MCU TX -> modem RXD |
| LTE PWRKEY control | GPIO5 | LTE_PWRKEY_CTL | N-MOS/NPN open-drain low-side |
| Buzzer PWM/ON | GPIO10 | BUZZER_CTL | transistor driver 권장 |
| Optional status input | GPIO4 or GPIO3 | LTE_STATUS_1V8 via level shift | SIM7080G STATUS 읽기 옵션 |
| Optional modem DTR | GPIO2 | LTE_DTR_1V8 via level shift | sleep mode 제어 옵션, 초기 DNP 가능 |
| Boot/USB native | module USB-C | programming/debug | SuperMini 자체 USB-C 유지 |

주의:

- XIAO bring-up 로그의 GPIO6/GPIO7 I2C는 검증 이력으로만 본다. 1차 PCB는 SuperMini 탑재가 확정이므로 GPIO8/GPIO9를 I2C 기본으로 사용한다.
- GPIO20/21은 현재 integrated firmware의 SuperMini env와 일치하게 유지한다.
- modem UART는 1.8 V라 level shifting이 필요하다. devkit UART 핀이 3.3 V tolerant처럼 동작했던 경험을 bare module에 적용하지 않는다.

## 7. 센서 회로 초안

### 7.1 I2C common bus

```text
3V3_REG
  -> 4.7 k pull-up to I2C_SDA_3V3
  -> 4.7 k pull-up to I2C_SCL_3V3
ESP32-C3 GPIO8/GPIO9
  -> TMP117
  -> MAX30102
```

초기값:

- Pull-up: 4.7 k to 3.3 V
- Test point: SDA, SCL, 3V3, GND
- Address:
  - TMP117: 0x48
  - MAX30102: 0x57

### 7.2 TMP117

- VIN -> 3V3_REG
- GND -> GND
- SDA/SCL -> I2C bus
- ADDR -> default 0x48. 필요시 solder jumper option reserve.
- INT -> test pad 또는 MCU spare pin option, 초기 DNP.
- 기구: skin-side thermal contact가 중요하다. LTE/modem/regulator 발열과 분리한다.

### 7.3 MAX30102

- VIN -> 3V3_REG
- GND -> GND
- SDA/SCL -> I2C bus
- INT -> test pad 또는 MCU spare pin option, 초기 DNP 가능.
- 기구: optical window, 차광, 피부 압력, sensor height가 성능을 좌우한다. 1차 PCB에서는 sensor를 board underside 또는 edge island에 배치하는 안을 우선 검토한다.

## 8. SIM7080G 회로 초안

필수 nets:

```text
VBAT_MODEM
GND
PWRKEY
STATUS optional
UART1_TXD / UART1_RXD
SIM_VDD / SIM_DATA / SIM_CLK / SIM_RST / SIM_DET optional
RF_ANT
GNSS_ANT
USB_DP / USB_DM / USB_VBUS test pads optional
BOOT_CFG test pad, keep open for normal boot
VDD_EXT test pad
```

PWRKEY:

- MCU GPIO5 -> gate/base drive -> N-MOS/NPN low-side pull-down.
- PWRKEY external pull-up 없음.
- Power-on pulse: 1.0 s 이상, 12.6 s 미만.
- Power-off pulse: 1.2 s 이상 또는 AT+CPOWD=1.
- PWRKEY를 GND에 영구 short하지 않는다.

UART level shift:

- ESP32-C3 3.3 V UART <-> SIM7080G 1.8 V UART.
- TX/RX 모두 level shifter 적용.
- 초기 회로는 2-channel auto-direction level translator보다 unidirectional UART용 translator 또는 reference BJT circuit을 우선 검토한다.

SIM holder:

- 1.8 V SIM 기준.
- SIM socket은 module 가까이 배치한다.
- SIM_VDD에 100 nF capacitor를 socket 가까이에 둔다.
- SIM_CLK는 짧고 GND guard 우선. branch 금지.
- SIM line ESD diode는 low-capacitance type.

## 9. Antenna / RF 배치 결정

1차 결정:

- LTE antenna connector: u.FL/IPEX.
- GNSS antenna connector: u.FL/IPEX.
- LTE RF_ANT와 GNSS_ANT는 별도 connector와 별도 50 ohm trace.
- 각 RF path에 PI matching network reserve:
  - series 0 ohm default
  - shunt C/L footprints DNP
- RF ESD TVS는 low capacitance 부품 footprint reserve.

배치 원칙:

- RF trace는 짧게, 50 ohm controlled impedance.
- right angle 금지, GND via fence 사용.
- LTE antenna와 GNSS antenna는 가능한 멀리 배치한다.
- SIM7080G hardware design checklist 기준 LTE main antenna와 GNSS antenna decoupling 목표는 30 dB 이상이다.
- GNSS active antenna를 쓸 가능성이 있으므로 GNSS antenna bias supply option footprint를 둔다. passive antenna만 쓸 경우 external LNA 필요성이 생기므로 1차 bring-up은 active GNSS antenna option을 더 현실적으로 본다.

## 10. Buzzer 회로 초안

권장:

```text
GPIO10 -> base/gate resistor -> N-MOS or NPN low-side switch -> active buzzer -> 3V3 or VBAT
```

- Active buzzer 사용.
- buzzer 정격 전류 확인 전까지 GPIO direct drive는 최종 schematic에서 피한다.
- magnetic buzzer라면 flyback diode 또는 적절한 clamp를 고려한다.
- Test point: BUZZER_CTL.

## 11. Debug / test point

필수 test points:

- GND multiple
- VBAT_RAW
- VBAT_MODEM near modem
- 3V3_REG
- I2C_SDA, I2C_SCL
- LTE_TXD_1V8, LTE_RXD_1V8
- MCU_UART_RX/TX 3.3 V side
- PWRKEY
- STATUS
- VDD_EXT
- BOOT_CFG, keep open
- SIM_VDD
- GNSS antenna bias rail if used

Debug connector:

- 1x6 or pads:
  - GND
  - 3V3
  - MCU TX
  - MCU RX
  - I2C SDA
  - I2C SCL
- SuperMini USB-C는 firmware upload/debug용으로 접근 가능해야 한다.

## 12. Schematic 작성 순서

1. Sheet 1: Title / system notes / design constraints
2. Sheet 2: Battery input, switch, protection, current-measure jumper
3. Sheet 3: 3.3 V regulator and decoupling
4. Sheet 4: ESP32-C3 SuperMini carrier footprint and headers
5. Sheet 5: SIM7080G module, VBAT bulk caps, PWRKEY, STATUS, UART level shift
6. Sheet 6: SIM holder and SIM ESD
7. Sheet 7: LTE antenna, GNSS antenna, matching networks, GNSS bias option
8. Sheet 8: TMP117 and MAX30102 I2C sensors
9. Sheet 9: Buzzer driver
10. Sheet 10: Test points and debug connector
11. ERC pass: power flags, level domains, no-connect pins, SIM/RF warnings 확인
12. Pre-layout checklist: power trace width, RF keepout, sensor placement, antenna separation, SuperMini USB access

## 13. Schematic freeze 전 확인 필요

부품/구매 확인:

- SIM7080G bare module 실제 구매처와 exact variant 확인.
- 1.8 V SIM이 현재 SKT physical SIM과 호환되는지 확인.
- u.FL/IPEX connector footprint와 antenna cable/antenna 확보.
- active GNSS antenna를 쓸지 passive GNSS antenna + LNA를 쓸지 결정.
- 3.3 V regulator part number와 peak/load 조건 확인.
- Li-Po pack 보호회로 내장 여부 확인.
- buzzer 정격 전류 확인.

전기 확인:

- SuperMini에 3V3 pin 직접 공급 시 onboard regulator/USB 연결과 충돌이 없는지 확인.
- SIM7080G UART level shifter 회로를 reference design 기준으로 확정.
- PWRKEY pulse 회로를 SPICE까지는 아니어도 logic-level 관점에서 검토.
- LTE attach/SMS/GNSS 중 VBAT_MODEM droop를 측정할 수 있도록 current shunt/test pads 준비.

기구 확인:

- MAX30102 optical window 위치.
- TMP117 thermal contact 위치.
- LTE/GNSS antenna 위치와 wrist 착용 시 인체/배터리/ground 영향.
- SIM holder 접근성.
- Li-Po 배터리 위치와 교체/충전 방식.

## 14. 사용한 외부 reference

- SIMCom SIM7080G official product page: https://www.simcom.com/product/SIM7080G.html
- SIM7080G Hardware Design V1.04 PDF: https://edworks.co.kr/wp-content/uploads/2022/04/SIM7080G_Hardware_Design_V1.04.pdf
- Quectel BG95 Series Hardware Design V1.5 PDF: https://images.quectel.com/python/2023/04/Quectel_BG95_Series_Hardware_Design_V1.5.pdf
- Quectel BG77 Hardware Design V1.3 PDF: https://images.quectel.com/python/2023/04/Quectel_BG77_Hardware_Design_V1.3.pdf
- Quectel BG770A-GL product/spec reference: https://static6.arrow.com/aropdfconversion/57cf8525af9901a4e073efe507a9298412b7cf4a/quectelbg770a-gl.pdf

## 15. 현재 회로 설계 결정 한 줄 버전

```text
1차 PCB는 ESP32-C3 SuperMini + SIM7080G bare SMT module + PCB SIM holder + LTE/GNSS u.FL antenna + Li-Po direct modem rail + separate 3.3 V rail 구조로 schematic 초안을 시작한다.
```

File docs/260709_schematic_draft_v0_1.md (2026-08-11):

# GCDP Heat Risk Alert Wristband - Schematic Draft v0.1

Date: 2026-07-09

Purpose: 최신 실험 로그와 현재 firmware 상태를 반영해 1차 PCB schematic 초안을 sheet별로 확정한다. 이 문서는 KiCad 회로도 작성 전의 회로 설계 기준이다.

## 0. 최신 실험 반영사항

최신 로그에서 확인된 사실:

- 센서 착용 상태에서 `worn=1`, TMP117 온도, MAX30102 RED/IR 값 정상 확인.
- SIM7080G 계열 보드에서 SKTelecom 등록, `CGATT: 1`, `CSQ 24~25` 확인.
- GNSS 좌표 포함 emergency-format SMS 전송 성공.
- `ALERTSMS 01000000000` 형태처럼 전화번호는 하이픈 없이 digits only로 넣어야 `AT+CMGS` prompt가 정상적으로 나온다.
- 하이픈 포함 번호는 `AT+CMGS` 단계에서 `ERROR`가 발생했다.
- GNSS 응답 예:

```text
+CGNSINF: 1,,,36.050000,127.330003,-19.819,,,1,,0.1,0.1,0.1,,,,191841.6,6000.0
```

- SMS 성공 응답:

```text
+CMGS: 8
OK
```

중요 해석:

- 최종 제품 기능 흐름인 sensor + GNSS + SMS는 firmware/모듈 레벨에서 검증됐다.
- 현재 PWRK 실험은 developer kit/CoreBoard 레벨의 PWRK 동작이다. 최종 bare SIM7080G module schematic은 반드시 SIM7080G Hardware Design의 PWRKEY reference를 따른다.
- 현재 최신 빌드 산출물은 `xiao_esp32c3` 기준이지만, 1차 PCB 목표 MCU는 ESP32-C3 SuperMini다. 회로도는 SuperMini pinout 기준으로 작성한다.

## 1. 1차 PCB 설계 목표 재정의

1차 PCB는 완성형 wearable이 아니라 다음을 검증하는 bring-up carrier board다.

```text
1. SIM7080G bare module 직접 실장 성공
2. Li-Po 기반 VBAT 전원에서 LTE/SMS/GNSS 안정 동작
3. ESP32-C3 SuperMini + SIM7080G UART/PWRKEY 제어
4. 기존 TMP117/MAX30102 sensor module 4-wire 연동
5. buzzer 경고 출력
6. RF/SIM/power debug 가능한 test point 확보
```

1차에서 하지 않는 것:

```text
충전회로
USB-C 충전
ESP32-C3 bare chip 설계
MAX30102/TMP117 IC 직접 실장
PCB antenna
eSIM/MFF2 SIM
상용 방수/최종 착용감 최적화
자동 SMS 무제한 활성화
```

## 2. Schematic Sheet 구성

```text
Sheet 1  SYS_NOTES
Sheet 2  BATTERY_POWER
Sheet 3  ESP32C3_SUPERMINI
Sheet 4  SIM7080G_MODEM
Sheet 5  SIM_CARD
Sheet 6  RF_LTE_GNSS
Sheet 7  SENSOR_4WIRE
Sheet 8  BUZZER
Sheet 9  TEST_DEBUG
```

## 3. Sheet 1 - SYS_NOTES

회로도 첫 장에 다음 설계 note를 넣는다.

```text
1st PCB is a bring-up carrier board.
MCU is ESP32-C3 SuperMini module, not bare ESP32-C3.
Modem is bare SIM7080G SMT module, not developer kit/CoreBoard.
No charging circuit on this PCB.
Use protected 1S Li-Po pack only.
SMS automatic sending remains disabled unless persistent rate-limit is implemented.
Phone number for AT+CMGS must be digits only, no hyphen.
```

전압 domain:

```text
VBAT_SYS       1S Li-Po raw battery rail, 3.0~4.2 V practical range
VBAT_MODEM     SIM7080G high-current rail, directly from VBAT_SYS
3V3            ESP32-C3 SuperMini, sensors, buzzer logic
1V8_MODEM      SIM7080G logic domain / VDD_EXT reference, do not load heavily
RF_LTE         50 ohm RF path
RF_GNSS        50 ohm RF path
```

## 4. Sheet 2 - BATTERY_POWER

### 4.1 Battery Input

Connector:

```text
J_BAT: 1.25 mm 2-pin Li-Po connector
Pin 1: VBAT_IN
Pin 2: GND
Battery target: TW-602035 Li-Po 380 mAh, protected pack preferred
```

Protection/minimum debug:

```text
F1: optional polyfuse or 0 ohm current-measure link
D1: optional reverse protection footprint, DNP if battery connector polarity is keyed and controlled
TP_VBAT_IN
TP_GND near battery connector
```

Decision:

- 물리 power switch는 1차에서 제외 가능.
- 단, current measurement를 위해 `0 ohm link` 또는 solder jumper는 반드시 둔다.
- 배터리 커넥터 탈착으로 hard power cycle 가능하게 한다.

### 4.2 Modem VBAT Rail

Net:

```text
VBAT_IN -> F1/current link -> VBAT_SYS -> VBAT_MODEM
```

SIM7080G VBAT decoupling, modem pin 근처:

```text
C_MODEM_BULK1: 100 uF low-ESR SMD, >=6.3 V
C_MODEM_10U1: 10 uF ceramic, >=6.3 V
C_MODEM_1U1: 1 uF ceramic
C_MODEM_100N1: 100 nF ceramic
C_MODEM_BACKUP: large electrolytic/polymer backup footprint, DNP default
  footprint should accept available 470 uF / 1000 uF / 2200 uF leaded capacitor by hand solder if needed
TP_VBAT_MODEM near SIM7080G VBAT pins
```

Layout note:

```text
VBAT_MODEM trace/polygon must be short and wide.
Place bulk capacitors as close as possible to SIM7080G VBAT pins.
Provide many GND vias around modem power capacitors.
```

### 4.3 3.3 V Rail

Regulator:

```text
U_3V3: 3.3 V LDO, >=500 mA, low dropout, not AMS1117
Candidate class: AP2112K-3.3 / ME6211-3.3 500mA / TLV75533 or equivalent
```

Generic schematic:

```text
VBAT_SYS -> U_3V3 VIN
U_3V3 VOUT -> 3V3
U_3V3 GND -> GND
U_3V3 EN -> VBAT_SYS through 100 k or tied to VIN if no EN sequencing needed
C_LDO_IN: 10 uF near VIN
C_LDO_OUT: 10 uF near VOUT
C_3V3_100N: 100 nF near each IC/module load
TP_3V3
```

Caution:

- SuperMini 3V3 pin 직접 공급은 USB 연결 시 역전류 가능성을 실제 보드에서 확인해야 한다.
- 회로에는 `R_SUPERMINI_3V3_LINK = 0 ohm`을 넣어 SuperMini 3V3 rail을 분리 가능하게 한다.

## 5. Sheet 3 - ESP32C3_SUPERMINI

Module:

```text
U_MCU: ESP32-C3 SuperMini module, soldered directly to carrier PCB
```

Power:

```text
3V3 -> R_SUPERMINI_3V3_LINK 0 ohm -> SuperMini 3V3
GND -> SuperMini GND
SuperMini 5V/VIN: NC by default
USB-C on SuperMini remains accessible for upload/debug
```

Final SuperMini pin map:

| Function | SuperMini GPIO | Net | Note |
| --- | --- | --- | --- |
| I2C SDA | GPIO8 | I2C_SDA_3V3 | SuperMini final PCB 기준 |
| I2C SCL | GPIO9 | I2C_SCL_3V3 | SuperMini final PCB 기준 |
| LTE UART RX | GPIO20 | MCU_RX_LTE_TX_3V3 | modem TXD -> MCU RX through level shifter |
| LTE UART TX | GPIO21 | MCU_TX_LTE_RX_3V3 | MCU TX -> modem RXD through level shifter |
| Modem PWRKEY control | GPIO5 | LTE_PWRKEY_CTL_3V3 | drives MOSFET gate |
| Buzzer | GPIO10 | BUZZER_CTL | MOSFET driver input |
| Optional spare | GPIO4 | TP_SPARE_GPIO4 | DNP/test pad |
| Optional spare | GPIO3 | TP_SPARE_GPIO3 | DNP/test pad |

Important:

- 현재 실험 firmware의 최신 빌드는 `xiao_esp32c3`일 수 있다. 하지만 PCB schematic은 SuperMini 최종 탑재 기준이므로 I2C는 GPIO8/GPIO9로 잡는다.
- 회로도에 `XIAO test wiring used GPIO6/GPIO7; final SuperMini uses GPIO8/GPIO9` note를 남긴다.

## 6. Sheet 4 - SIM7080G_MODEM

Module:

```text
U_MODEM: SIM7080G LCC+LGA 77-pin SMT module
```

### 6.1 Power Pins

```text
VBAT pins -> VBAT_MODEM
All GND pins -> solid GND plane
VDD_EXT -> TP_VDD_EXT only, do not use as power source for external loads except level reference if reference design allows
```

### 6.2 PWRKEY

Final bare module circuit:

```text
ESP32 GPIO5 / LTE_PWRKEY_CTL_3V3
  -> R_GATE_PWRKEY 100 ohm~1 k
  -> Q_PWRKEY gate
Q_PWRKEY: small N-MOSFET, source=GND, drain=SIM7080G_PWRKEY
R_GATE_PD: 100 k from gate to GND
SIM7080G_PWRKEY has no external pull-up
TP_PWRKEY on SIM7080G_PWRKEY net
```

Firmware polarity for final bare module:

```text
GPIO HIGH -> MOSFET ON -> PWRKEY pulled LOW
GPIO LOW/input -> PWRKEY released
```

Timing:

```text
Power on: pull PWRKEY LOW for about 1.0~2.0 s
Power off: prefer AT+CPOWD=1; PWRKEY low pulse may be used as fallback
```

Critical note:

- Developer kit/CoreBoard에서 GPIO5에 3.3 V를 1~2초 인가하면 켜지는 동작은 board-level PWRK behavior다.
- Bare SIM7080G module의 PWRKEY는 1.8 V internal pull-up active-low input으로 설계한다.
- 최종 schematic에서는 GPIO가 PWRKEY에 3.3 V를 직접 밀어 넣지 않는다.

### 6.3 UART

SIM7080G UART domain:

```text
SIM7080G TXD/RXD: 1.8 V logic domain
ESP32-C3 UART: 3.3 V logic domain
```

Required circuit:

```text
MCU_TX_LTE_RX_3V3 -> level shift down -> LTE_RXD_1V8 -> SIM7080G RXD
SIM7080G TXD -> LTE_TXD_1V8 -> level shift up -> MCU_RX_LTE_TX_3V3
```

Schematic implementation:

- Use a 2-channel unidirectional level translator or discrete reference transistor circuit.
- Add small series resistors if recommended by selected translator:

```text
R_UART_MCU_TX: 33~100 ohm optional
R_UART_MCU_RX: 33~100 ohm optional
TP_MCU_TX_3V3
TP_MCU_RX_3V3
TP_LTE_TXD_1V8
TP_LTE_RXD_1V8
```

Do not:

- Do not copy developer kit UART electrical level blindly.
- Do not connect ESP32 3.3 V TX directly into SIM7080G RXD unless the exact target module documentation proves tolerance.

### 6.4 Optional Modem Pins

Connect as test pads only:

```text
STATUS -> TP_STATUS
NETLIGHT -> TP_NETLIGHT
DTR -> TP_DTR
1PPS -> TP_1PPS
USB_DP -> TP_USB_DP
USB_DM -> TP_USB_DM
USB_VBUS -> TP_USB_VBUS or NC if routing is too tight
BOOT_CFG -> TP_BOOT_CFG, keep open for normal boot
RESET_N -> NC or TP_RESET_N only, no MCU control in v0.1
```

Rationale:

- SIM7080G 직접 실장 후 debug 접근성이 매우 중요하다.
- 하지만 STATUS/DTR/NETLIGHT까지 MCU에 연결하면 firmware/schematic 복잡도가 늘어난다.

## 7. Sheet 5 - SIM_CARD

SIM holder:

```text
J_SIM: internal nano-SIM holder
SIM_DET not used
```

Connections:

```text
SIM_VDD -> SIM holder VCC
SIM_DATA -> SIM holder IO
SIM_CLK -> SIM holder CLK
SIM_RST -> SIM holder RST
GND -> SIM holder GND/shield
```

Capacitor:

```text
C_SIM_VDD: 100 nF close to SIM holder VCC/GND
```

ESD:

```text
D_SIM_ESD: low-capacitance SIM ESD array on SIM_DATA/SIM_CLK/SIM_RST/SIM_VDD
```

Layout:

```text
SIM holder close to SIM7080G.
SIM_CLK short, no branch, no unnecessary test pad.
No SIM line test pads in v0.1 unless routing/debug absolutely requires them.
```

Note:

- SIM7080G documentation indicates 1.8 V SIM operation. Confirm physical SKT SIM compatibility remains acceptable.

## 8. Sheet 6 - RF_LTE_GNSS

### 8.1 LTE Antenna Path

```text
SIM7080G RF_ANT -> LTE PI matching -> J_LTE_UFL
```

PI matching default:

```text
R/L_SER_LTE: 0 ohm default
C_SHUNT_LTE_IN: DNP
C_SHUNT_LTE_OUT: DNP
D_LTE_ESD: low-capacitance RF ESD, DNP or installed depending part availability
```

### 8.2 GNSS Antenna Path

```text
SIM7080G GNSS_ANT -> GNSS PI matching -> J_GNSS_UFL
```

PI matching default:

```text
R/L_SER_GNSS: 0 ohm default
C_SHUNT_GNSS_IN: DNP
C_SHUNT_GNSS_OUT: DNP
D_GNSS_ESD: low-capacitance RF ESD, DNP or installed depending part availability
```

GNSS active antenna option:

```text
Reserve L/C/R bias tee footprint if active GNSS antenna is selected.
Default v0.1 can leave GNSS bias DNP until antenna part is selected.
TP_GNSS_BIAS if bias rail exists.
```

Connector:

```text
J_LTE_UFL: U.FL/IPEX/MHF compatible SMT connector
J_GNSS_UFL: same connector family as LTE if possible
Silkscreen: LTE, GNSS
```

Layout:

```text
50 ohm controlled impedance.
Prefer 4-layer PCB.
GND plane continuous under RF path.
Via fence near RF trace.
No right-angle RF routing.
Keep LTE and GNSS antenna connectors separated as much as board size allows.
```

## 9. Sheet 7 - SENSOR_4WIRE

Decision:

- 1차 PCB에서 MAX30102/TMP117 IC 직접 실장하지 않는다.
- 기존 sensor modules를 별도 skin-side sensor assembly로 유지한다.
- Main PCB에는 4-wire solder pads만 둔다.

Pads:

```text
J_SENSOR_PAD_1: GND
J_SENSOR_PAD_2: 3V3
J_SENSOR_PAD_3: I2C_SDA_3V3
J_SENSOR_PAD_4: I2C_SCL_3V3
```

I2C pull-up:

```text
R_I2C_SDA: 4.7 k to 3V3, DNP/install option
R_I2C_SCL: 4.7 k to 3V3, DNP/install option
```

Default assembly:

- If sensor modules already have pull-ups, leave R_I2C_SDA/R_I2C_SCL DNP first.
- If I2C rise time or cable length causes errors, install 4.7 k or adjust to 10 k / 2.2 k after measurement.

Test points:

```text
TP_SDA
TP_SCL
TP_SENSOR_3V3
TP_SENSOR_GND
```

Cable:

```text
4-wire soldered cable, target 5~8 cm, avoid >10 cm.
Use strain relief with glue/epoxy/UV resin after soldering.
```

Note:

- Live test showed I2C transient errors can occur during LTE/status operations, but firmware recovered. Schematic should preserve I2C test pads and optional pull-up footprints.

## 10. Sheet 8 - BUZZER

Decision:

- Use MOSFET low-side driver, not direct GPIO drive.

Circuit:

```text
GPIO10 / BUZZER_CTL -> R_BUZZ_GATE 100 ohm~1 k -> Q_BUZZ gate
R_BUZZ_PD 100 k gate to GND
Q_BUZZ source -> GND
Q_BUZZ drain -> buzzer negative
Buzzer positive -> 3V3 or VBAT_SYS depending buzzer rated voltage
```

Default:

- If using existing 3.3 V active buzzer, connect buzzer positive to 3V3.
- If buzzer is louder/works better from Li-Po and rated for 3~5 V, provide solder jumper option:

```text
JP_BUZZ_PWR selects 3V3 or VBAT_SYS
Default: 3V3
```

Protection:

- Active piezo buzzer usually does not need flyback diode.
- If magnetic buzzer is selected, add diode/clamp footprint.

Test:

```text
TP_BUZZER_CTL
```

## 11. Sheet 9 - TEST_DEBUG

Minimum test pads:

```text
TP_GND x multiple
TP_VBAT_IN
TP_VBAT_MODEM near modem
TP_3V3
TP_PWRKEY
TP_MCU_TX_3V3
TP_MCU_RX_3V3
TP_LTE_TXD_1V8
TP_LTE_RXD_1V8
TP_STATUS
TP_NETLIGHT
TP_DTR
TP_1PPS
TP_VDD_EXT
TP_SDA
TP_SCL
TP_SIM_VDD
TP_USB_DP
TP_USB_DM
```

Optional debug header:

```text
J_DEBUG 1x6 pads:
1 GND
2 3V3
3 MCU_TX
4 MCU_RX
5 I2C_SDA
6 I2C_SCL
```

Note:

- SuperMini USB-C must remain physically reachable. This is the primary upload/debug path.
- Do not rely on SIM7080G USB for normal bring-up; keep pads only.

## 12. PCB Layer Decision

Recommendation:

```text
Use 4-layer PCB if budget/manufacturing allows.
```

Reason:

- SIM7080G direct SMT + LTE/GNSS RF + high-current modem bursts are a lot for a first board.
- 4-layer gives a stable GND plane and easier RF/power return path.

Suggested stack:

```text
L1: components / signals / RF
L2: solid GND plane
L3: power + low-speed signals
L4: signals / GND pour
```

If forced to 2-layer:

- Still possible, but RF and modem power margin shrinks.
- Use large GND pours, aggressive via stitching, short RF traces, and keep modem power path very compact.

## 13. Schematic Freeze Checklist

Before KiCad schematic freeze:

```text
[ ] SIM7080G exact footprint verified from hardware design package
[ ] SMT vendor can assemble SIM7080G LCC+LGA 77-pin module
[ ] SuperMini 3V3 direct supply / USB back-power risk checked
[ ] 1.8 V UART level shifter circuit selected
[ ] 3.3 V LDO exact part selected
[ ] Nano-SIM holder exact part selected
[ ] SIM ESD array selected
[ ] U.FL/IPEX connector exact part selected
[ ] LTE antenna selected
[ ] GNSS antenna selected, active/passive/bias decided
[ ] 380 mAh battery pulse discharge capability checked
[ ] Buzzer rated voltage/current checked
[ ] 4-layer PCB cost/lead time accepted
```

## 14. Current Schematic Decision Summary

```text
Battery: TW-602035 1S Li-Po, no charger, no switch, current-link/test pads included
Power: VBAT direct to SIM7080G, separate 3.3 V LDO for MCU/sensors
MCU: ESP32-C3 SuperMini, soldered directly, USB accessible
Modem: SIM7080G bare SMT, PWRKEY through N-MOS open-drain pull-down
UART: 3.3 V <-> 1.8 V level shifting required
SIM: internal nano-SIM holder, SIM ESD, no SIM_DET
RF: LTE and GNSS U.FL/IPEX connectors, PI matching footprints
Sensors: external existing MAX30102/TMP117 modules via 4-wire solder pads
Buzzer: GPIO10 through MOSFET low-side driver
Debug: generous test pads for power, UART, PWRKEY, modem auxiliary pins, I2C
PCB: 4-layer preferred
```

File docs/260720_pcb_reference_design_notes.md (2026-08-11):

# Current Design Notes - Wired Wearable Prototype

Date: 2026-07-20

## Architecture

```text
Sensors:
  TMP117 + MAX30102 on shared I2C

MCU:
  ESP32-C3 SuperMini

LTE/SMS:
  M5Stack Stamp CatM S003, SIM7080G-based, communication only

GPS:
  Beitian BE-220 GPS/GNSS module, separate UART

Power:
  TW-602035 Li-Po battery, external charging

Case:
  TPU printed wearable holder/band
```

## Fixed Module Data

### ESP32-C3 SuperMini

```text
Use as development-board/module controller.
USB-C must remain accessible.
Do not move to bare ESP32-C3 chip for this prototype.
```

Target pin plan:

```text
GPIO8  -> I2C SDA
GPIO9  -> I2C SCL
GPIO20 -> LTE UART RX
GPIO21 -> LTE UART TX
GPIO10 -> Buzzer
GPIO5  -> LTE PWRK/wake if needed
GPIO4  -> Standalone trigger, active-low to GND
GPIO6/GPIO7 or GPIO3/GPIO2 -> GPS UART candidate
```

### Cat-M LTE/SMS Module

```text
Use M5Stack Stamp CatM S003 rather than the large SIM7080G developer board.
Expected role: LTE registration and SMS.
No GNSS dependency.
UART: 115200 8N1.
Keep LTE antenna clear of battery/body/metal as much as possible.
```

### BE-220 GPS

```text
Model: Beitian BE-220
Size: 22 x 20 x 6 mm
VCC: 3.6 V to 5.5 V, typical 5.0 V
Current: about 15 mA at 5 V
Default baud: 38400 bps
Protocol: NMEA/UBX
Pinout: GND, TX, RX, VCC
```

Placement:

```text
Patch antenna faces outward/upward.
Do not place under battery.
Avoid metal above/around GPS patch.
Keep separate from LTE antenna where possible.
```

### TMP117

```text
Use existing breakout/module.
I2C address: 0x48.
Use VIN/GND/SDA/SCL only.
Place near skin contact, away from LTE heat.
```

### MAX30102

```text
Use existing breakout/module.
I2C address: 0x57.
Use VIN/GND/SDA/SCL only.
Must be flush to skin and light-blocked.
```

### Battery

```text
TW-602035 Li-Po
3.7 V nominal
380 mAh
20 x 35 x 6 mm
1.25 mm 2-pin connector
External charging only
```

### Buzzer / Trigger

```text
Buzzer: 3 V active buzzer on GPIO10.
Trigger: GPIO4 active-low to GND, hold about 1.5 s for standalone alert.
```

## Preserved Validation Results

The record logs under the N: workspace remain authoritative for validation history:

```text
260708_hardware_bringup_log.md
260709_lte_sms_integrated_firmware_log.md
260713_battery_standalone_alert_test_log.md
```

Current verified functions:

```text
TMP117 temperature read
MAX30102 RED/IR and wear detection
Buzzer feedback
LTE registration
SMS transmission
GNSS/location acquisition on previous SIM7080G test path
Battery-powered standalone alert flow
```

Next firmware change:

```text
Use BE-220 NMEA GPS data instead of SIM7080G GNSS commands for the final wired wearable.
```

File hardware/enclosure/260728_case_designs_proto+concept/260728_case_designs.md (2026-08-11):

# 260728 Case Designs: Prototype (fits current modules) + Concept (ideal final)

Author: Donggyu An (Aiki)
Date: 2026-07-28
Basis: 260713 team progress/specs doc + 260718 GPS/LTE module update

Two versions in this package:

```text
A. PROTOTYPE (proto_*)   fits the modules we have RIGHT NOW, jumper wiring OK,
                         roomy, screw-open lid, print and use immediately
B. CONCEPT   (concept_*) the "later final version" target from the 260713 doc,
                         assumes an integrated PCB - design direction, not a fit
                         for current breakout boards
```

## Files

```text
proto_case.scad       parametric source for the prototype case
proto_base.stl        prototype body (print as-is, bottom on bed)
proto_lid.stl         prototype lid (engraved face up)
proto_preview.png / proto_layout.png   renders (layout = top view of bays)

concept_case.scad     parametric source (OpenSCAD, free: openscad.org)
concept_shell.stl     main body - print upside down (top face on bed), supports for lugs
concept_bottom.stl    skin-side sensor plate - snap-fit into shell
concept_preview.png / concept_bottom.png / concept_exploded.png   renders
```

## A. Prototype version — 105 x 75 x 24 mm

Single-level layout, every module in its own fenced bay, 20 mm internal height
for jumper-wire slack. Lid opens with 4x M2 self-tapping screws for debugging.

```text
Layout (top view):        rear
  [LTE reserve 26x28] [battery pocket] [BE-220 GPS, open sky above]
  [                 ] [              ] [TP4056 charge bay -> USB hole in +X wall]
  [ESP32, USB-C hole in -X wall] [MAX30102, floor window + shroud] [TMP117]
                            front (skin side)
```

- MAX30102: 9x7 through-window in the floor, external black light-shroud rim,
  centered where strap pressure is stable
- TMP117: 0.8 mm thermal membrane in the floor, placed diagonally opposite the
  LTE bay (max heat separation). Note: TP4056 bay is ~3.5 mm away - ignore
  temperature readings while charging
- LTE bay is oversized (26x28) because the module is TBD - M5Stamp CatM,
  Waveshare SIM7080G mini boards etc. all fit. When confirmed, edit
  lte_pos / lte_sz in proto_case.scad and re-export
- Lid: trigger button hole (GPIO4), reset access hole, 7 buzzer sound holes,
  engraved label. Strap: 26 mm velcro loops on both long sides
- Assembly shopping list: 4x M2x8 screws, 25 mm velcro, 6x6 tactile switch,
  TP4056 (USB-C version), hot glue / foam tape

## Key specs

```text
Body: 48 x 44 x 16 mm, rounded (r11), curved underside R45 to fit the wrist
Band: standard 24 mm watch band, integrated lugs, 1.3 mm spring bars
Internal stack (bottom to top):
  1. Skin plate: MAX30102 optical window 8x6 with black light-shroud ring groove,
     TMP117 thermal island (0.6 mm membrane), sensor pod raised 1.2 mm
     for stable skin pressure
  2. Integrated main PCB 38 x 33 (ESP32-C3 + LTE Cat-M + charge IC assumed on board)
  3. Battery 380 mAh (20x35x6) and BE-220 GPS (22x20x6) side by side on the PCB
     GPS sits under a 0.8 mm skylight in the top face (ceramic patch facing up,
     no metal above)
Controls: recessed top trigger button (accident-proof), side USB-C,
          buzzer micro-slits on the opposite side
```

## Design decisions carried over from our docs

- TMP117 thermally separated from LTE (LTE on PCB edge away from thermal island)
- MAX30102 flush to skin, light-blocked, centered pressure
- Battery never presses the optical sensor, no metal over the GPS patch
- SMS/debug requirements unchanged

## What is still parametric / open

- LTE module: assumed integrated on the main PCB. If we end up using a separate
  LTE breakout, this concept needs a thickness bump (16 -> ~18 mm) - one
  parameter change in the scad file.
- Charging: assumed on-board charge IC via the side USB-C.
- All dimensions are variables at the top of the .scad file - easy to tweak.

## Print notes

- Black PLA/PETG recommended (light blocking around the optical window matters)
- 0.2 mm layers, 3 walls; shell printed top-face-down with lug supports

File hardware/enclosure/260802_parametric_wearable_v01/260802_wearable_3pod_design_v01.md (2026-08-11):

# 260802 Wearable 3-Pod Design v0.1

## 1. Fixed Inputs

- Wrist circumference: 165 mm
- Provisional wrist ellipse: 59 x 46 mm
- Calculated ellipse circumference: 165.57 mm
- Physical strap type: buckle-assisted hook-and-loop strap
- Strap width: 25 mm (2.5 cm)
- Provisional strap thickness: 2.0 mm
- Strap running clearance: 0.6 mm
- Normal start method: MAX30102 wear/contact detection; no external start button
- Enclosure wall, floor, lid, and structural features: 2.0 mm throughout

The wrist ellipse is only a packaging and curvature reference. Fit is adjusted by
the physical hook-and-loop strap, so the printed parts do not form a rigid cuff.

## 2. Architecture Decision

Final prototype architecture fixed on 2026-08-02: a narrow segmented strap,
not a watch body or a rigid cuff.

```text
Outer/top surface around wrist:
  [POWER link] -- flexible gap -- [GPS link] -- flexible gap -- [LTE link]

Skin surface:
  [MAX30102 contact tile] -- soft strap -- [TMP117 contact tile]

Outer return strap:
  [50 x 25 mm LTE film antenna sleeve]
```

Fixed placement rules:

- All rigid links follow the wrist circumference. Their long axis is tangent to
  the wrist, not parallel to the forearm.
- Maximum visible link width across the forearm is 25.2 mm. This matches the
  purchased 25 mm hook-and-loop strap and prevents a bold watch-like silhouette.
- The strap remains continuous and acts as the hinge. Printed links do not use
  mechanical hinge pins and do not form a rigid ring.
- Nominal flexible gap between adjacent upper links is 5 mm.
- GPS remains the dorsal center link with its ceramic patch facing outward.
- POWER sits on one dorsal flank and LTE on the opposite dorsal flank.
- The LTE antenna is not inside a pod. It sits in a thin non-metallic sleeve on
  the outward-facing return section of the strap.
- MAX30102 and TMP117 remain separate skin-contact tiles. Neither is stacked
  behind GPS, LTE, the battery, or the ESP32.

POWER link internal arrangement:

- 220 mAh battery lies flat at the bottom.
- ESP32-C3 keeps its long axis along the wrist circumference and is placed above
  the battery. The verified public slim case demonstrates an approximately
  20.8 mm external width in this orientation.
- The buzzer forms a tapered terminal region after the ESP32 instead of widening
  the link or becoming a third full vertical layer.
- USB-C faces a forearm-side service opening.
- Battery lead and external-charge connector remain accessible under the lid.

The enclosure language is a set of related rounded shingles: constant width,
large end radii, tapered lower edges, and no vertical box walls visible from the
normal viewing angle.

Wall policy:

- Use 2.0 mm uniformly for side walls, floor, lid, strap features, cable exits,
  and local structural regions.
- Do not introduce separate wall-thickness classes in the camp prototype.
- A 20.0 mm-wide module with 0.4 mm clearance per side and 2.0 mm walls produces
  a 24.8 mm outer width, remaining within the narrow 25 mm strap target.

## 3. Narrow-Link Target Envelopes

Axis convention: circumference length x forearm width x radial thickness.
These are v0.2 design targets, not final print-fit dimensions.

| Link | Target outer envelope (mm) | Notes |
| --- | ---: | --- |
| POWER: 220 mAh + ESP32 + buzzer | 35 x 22 x 15 max | ESP long axis follows wrist; narrow buzzer terminal after ESP |
| GPS: BE-220 only | 25 x 24 x 9.5 | Patch outward; no stacked electronics |
| LTE: Stamp CatM only | 34 x 24 x 9.5 | SIM and U.FL service access retained |
| MAX30102 contact tile | 24 x 19 x 4 target | Optical window and black light-blocking ring on skin side |
| TMP117 contact tile | 20 x 27.5 x 4 target | Board rotated across strap; connector removed for low profile |

Three upper links plus two 5 mm gaps occupy about 100 mm of wrist circumference.
The remaining circumference stays flexible for the sensor tiles, buckle, and fit
adjustment. The LTE film antenna uses the overlapping outer return strap and is
not counted as another rigid link.

Battery decision (fixed 2026-08-02):

- Use the TW-602025 220 mAh Li-Po for the wearable prototype.
- Physical battery measurement: 28 x 20 x 6 mm, 3.7 V.
- CAD axis convention: length = 28 mm, width = 20 mm, height = 6 mm.
- The 150 mAh battery provides too little packaging benefit to justify its lower
  capacity, so it is no longer the primary design candidate.
- The 380 mAh battery has already powered repeated bench tests without recharge,
  demonstrating that the prototype workload is modest, but its 35 mm length is
  rejected for the wearable enclosure because of size.
- The battery + ESP + buzzer pod must be revised from the current 150 mAh height
  assumption to the 220 mAh envelope before the fit print.

Buzzer allowance:

- Measured cylindrical body: 9.1 mm diameter x 5.9 mm high.
- CAD envelope: 9.7 mm diameter x 6.5 mm high, excluding full lead length.
- The battery + ESP pod has a separate 10.2 mm end zone for the buzzer, keeping
  the pod at the 40 mm wrist-length target without adding another vertical layer.

## 4. Lower Sensor Region

The previous rigid 51 mm sensor bar is rejected. Use two independent low-profile
contact tiles on the skin side of the continuous strap:

- MAX30102 optical tile near the lower center of the wrist.
- TMP117 tile offset from MAX30102 and away from POWER/LTE heat.

The next revision must add:

- MAX30102 optical opening and black light-blocking ring
- TMP117 thermal contact island
- soft gasket/TPU contact feature
- four-wire I2C cable exit and strain relief
- direct-soldered thin wires after removing protruding headers/connectors

## 5. Strap and Buckle Integration

- The existing buckle remains part of the purchased strap and is not printed.
- Each upper pod uses an open-ended, low-profile strap cradle.
- The free strap end passes through the existing buckle and folds back, matching
  the current tourniquet-style fastening method.
- The current 2.0 mm strap thickness is provisional. Measure the compressed and
  uncompressed thickness before the first fit print.

## 6. Exported CAD

Fusion-compatible STEP and print-oriented STL files are in `exports/`.

- Full 3-pod layout: `260802_layout_3pod_v01.step`
- Rejected 2-pod comparison: `260802_layout_2pod_comparison_v01.step`
- Wrist/strap reference: `260802_wrist_165mm_strap_25mm_reference.step`
- Individual base/lid files for battery + ESP, GPS, and Stamp CatM
- Lower sensor-bar envelope

The individual STL bodies were checked as watertight. The v0.1 lids are flat
fit-test covers without snap hooks; use tape-assisted retention for the first
physical layout test.

## 7. Milestone Status

| Milestone | Status | Result |
| --- | --- | --- |
| M1 Functional hardware proof | Complete | Sensors, GPS, Cat-M, SMS, battery operation previously demonstrated |
| M2 Mechanical dimensions | Mostly complete | 220 mAh battery fixed and measured; strap thickness and buckle dimensions remain |
| M3 Wearable architecture | Complete | Narrow segmented strap: 3 upper links + 2 skin tiles + return-strap antenna |
| M4 Parametric CAD blockout | Revision required | v0.1 proved volume; v0.2 must rotate links tangent to wrist and use 220 mAh dimensions |
| M5 Fit print and physical placement | Pending v0.2 | Print link bases, thread the 25 mm strap, place real modules |
| M6 Detail enclosure revision | Pending | Ports, wire exits, sensor openings, retention, and strain relief |

## 8. Immediate Next Work

1. Rebuild the Fusion v0.2 blockout with every upper link tangent to the wrist.
2. Revise POWER for the measured 28 x 20 x 6 mm battery, longitudinal ESP, and
   tapered buzzer terminal.
3. Add separate MAX30102 and TMP117 skin-contact tile envelopes.
4. Add the LTE antenna sleeve to the outward return strap.
5. Measure strap thickness and buckle outer dimensions.
6. Print only the link bases and sensor-tile carriers first.
7. Thread the actual strap, place real modules, and record cable and pressure issues.

## 9. Dual-Axis Hinge Reference Measurement (2026-08-03)

The selected reference STL uses a dual-axis hinge with an extra intermediate
piece. Each case-to-case connection therefore has two rotation axes rather than
one direct pivot axis.

Direct measurements from the reference STL, following the numbered hinge
segments 1 through 5 shown in the inspection image:

```text
Segment 1: 68.5
Segment 2: 97.25
Segment 3: 68.5
Segment 4: 97.25
Segment 5: 68.5
```

Observed pattern:

```text
68.5 / 97.25 / 68.5 / 97.25 / 68.5
```

The measured spacing between the corresponding reference objects is 3 mm.
These values are recorded as direct reference-STL observations. Final prototype
hinge dimensions and print clearances have not yet been frozen from these
measurements.

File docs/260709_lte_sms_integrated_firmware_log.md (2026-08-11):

# 2026-07-09 LTE/SMS and Integrated Firmware Log

Project: Heat Risk Alert Wristband  
Purpose: Validate physical SIM, SKT network registration, SMS transmission, and transition from bring-up sketches to integrated firmware.

## 1. SIM and LTE Network Test

### SIM

A physical SIM was activated on the SKT network and inserted into the SIM7080G developer kit.

Sensitive identifiers are intentionally masked in this log.

### Modem and UART

The SIM7080G developer kit communicated with the ESP32-C3 over UART.

Confirmed UART configuration:

```text
ESP32-C3 RX = GPIO20
ESP32-C3 TX = GPIO21
Baud = 115200
```

The SIM7080G responded to AT commands.

Observed:

```text
AT -> OK
ATI -> R1951.07 / OK
AT+CPIN? -> +CPIN: READY / OK
```

### Antenna and Signal

Before antenna connection:

```text
AT+CSQ -> +CSQ: 99,99
AT+CEREG? -> +CEREG: 0,2
```

After antenna connection:

```text
AT+CSQ -> +CSQ: 23 to 26,99
```

Conclusion: antenna connection was required for practical network reception.

### Network Registration

The modem successfully registered on SKT.

Observed successful registration:

```text
AT+CEREG? -> +CEREG: 2,1,...
AT+COPS?  -> +COPS: 0,2,"45005",7
AT+CGATT? -> +CGATT: 1
```

Conclusion:

- SKT network registration succeeded.
- The working PLMN was `45005`.
- Manual attempt with `45012` failed with no network service.

### Modem Mode

The modem was set to Cat-M preferred mode:

```text
AT+CMNB=1
```

The modem reported:

```text
AT+CNMP? -> +CNMP: 38
AT+CBAND? -> +CBAND: ALL_MODE
```

## 2. SMS Transmission Test

### Test Message

A test SMS was sent from the SIM7080G module to a separate phone number.

Message body:

```text
GCDP SIM7080G SMS TEST
```

The receiving phone confirmed that the SMS was received.

### Safety Issue Found

The initial SMS test firmware used a one-shot flag stored only in RAM. Because the flag resets after firmware reset, the message could be sent again after re-upload or reset.

This caused duplicate test SMS reception.

### Safety Fix

Automatic SMS sending was disabled.

The integrated firmware now sends SMS only when a manual serial command is entered:

```text
SMS <number> <message>
```

No SMS is sent automatically during boot, reset, network registration, or state-machine operation.

## 3. Integrated Firmware

The firmware was rewritten from separate diagnostic sketches into one integrated firmware file:

```text
C:\Users\sukhe\Desktop\GCDP_codex_temp\firmware\src\main.cpp
```

Implemented components:

- I2C sensor initialization and scanning
- TMP117 temperature reading
- MAX30102 RED/IR sampling
- IR-threshold-based wear detection
- active buzzer control
- LTE modem initialization
- LTE status polling
- manual SMS command
- basic state machine

## 4. State Machine

Implemented states:

```text
BOOT
NOT_WORN
NORMAL
SUSPECT
ALARM
EMERGENCY_READY
ERROR
```

Current behavior:

- No contact: `NOT_WORN`
- Contact detected by MAX30102 IR threshold: `NORMAL`
- Temperature above threshold for confirmation period: `SUSPECT`
- Sustained abnormal condition: `ALARM`
- Alarm duration elapsed: `EMERGENCY_READY`
- Sensor failure persistence: `ERROR`

The current emergency workflow does not automatically send SMS. SMS sending remains manual for safety during development.

## 5. Wear Detection

Wear detection uses MAX30102 IR intensity with hysteresis and consecutive-sample confirmation.

Thresholds:

```text
wear on  threshold: 80000
wear off threshold: 60000
confirmation count: 3
```

Observed:

```text
[wear] detected ...
[state] NOT_WORN -> NORMAL
[wear] removed ...
[state] NORMAL -> NOT_WORN
```

## 6. LTE Status in Integrated Firmware

The integrated firmware successfully maintained LTE status monitoring.

Observed:

```text
lte_reg = 1
csq = 22 to 23
CPIN READY
COPS 45005
CGATT 1
```

## 7. Sensor Stability Adjustment

During integrated testing, occasional I2C read failures occurred. The first integrated version treated transient I2C failures as immediate `ERROR` conditions, which caused state flapping.

Adjustment:

- TMP117 must fail repeatedly before `ERROR`.
- MAX30102 must fail repeatedly before `ERROR`.
- Last valid readings are retained through short transient failures.
- Implausible TMP117 readings outside the expected sensor range are rejected.

After adjustment, the firmware maintained stable `NOT_WORN` and `NORMAL` states during regular operation.

## 8. Current Confirmed Capabilities

Confirmed:

- ESP32-C3 integrated firmware upload
- TMP117 read
- MAX30102 read
- wear detection
- buzzer control
- SIM7080G AT communication
- SKT network registration
- packet attach
- actual SMS transmission
- manual-only SMS safety lock

Not yet completed:

- automatic emergency SMS workflow
- GNSS/GPS acquisition
- Li-Po battery operation
- LTE transmission power stability test
- PCB schematic
- final threshold tuning

## 9. Next Recommended Steps

1. Add a manual emergency simulation command:

```text
ALARM
CANCEL
```

2. Add a manual SMS command test only when intentionally needed:

```text
SMS <number> <message>
```

3. Implement GNSS test:

```text
GNSS power on
location query
timeout handling
last-known-location fallback
```

4. Prepare circuit-design notes:

- ESP32-C3 pin map
- I2C bus
- SIM7080G UART
- SIM7080G PWRK control
- buzzer pin
- LTE antenna requirement
- GNSS antenna requirement
- power rail requirements
- LTE current spike mitigation

## 10. GNSS Test

GNSS test commands were added to the integrated firmware.

Serial commands:

```text
GNSS
GNSSOFF
```

Observed GNSS command sequence:

```text
AT+CGNSPWR=1
OK
AT+CGNSINF
+CGNSINF: 1,,,36.050000,127.330003,-19.819,,,1,,0.1,0.1,0.1,,,,191841.8,6000.0
OK
[gnss] coordinate acquired
```

Result:

- SIM7080G GNSS command path worked.
- GNSS coordinate fields were returned.
- Firmware was adjusted to treat valid latitude/longitude fields as coordinate acquisition, because the module response did not always return the simple `+CGNSINF: 1,1` pattern.
- GNSS was turned off after the test:

```text
AT+CGNSPWR=0
OK
```

Note:

- GNSS reliability should be retested outdoors or near a window.
- The developer kit has multiple antenna connectors; the final board must clearly separate LTE antenna and GNSS antenna requirements.

## 11. Modem PWRK Control Preparation

Firmware support was added for MCU-controlled SIM7080G PWRK pulsing.

Temporary development pin assignment:

```text
ESP32-C3 GPIO5 -> SIM7080G DevKit PWRK
ESP32-C3 GND   -> SIM7080G DevKit GND
```

Serial command:

```text
MODEMPWR
```

Behavior:

- The firmware pulls `LTE_PWRK_PIN` LOW for about 1.8 seconds.
- After the pulse, the pin is released back to input/high-impedance mode.
- This mimics the manual PWRK-to-GND activation previously used.

Implemented build flag for the XIAO ESP32-C3 environment:

```text
LTE_PWRK_PIN=5
```

Result:

- Firmware built and uploaded successfully after adding PWRK control.
- Command list verified:

```text
HELP | STATUS | LTE | GNSS | GNSSOFF | MODEMPWR | ALARM | CANCEL | SMS <number> <message>
```

Pending:

- Physical PWRK wire test remains pending until `SIM7080G DevKit PWRK` is connected to `ESP32-C3 GPIO5`.
- Final PCB should not rely on a direct push-pull drive for PWRK. Use an open-drain style transistor/MOSFET interface or equivalent safe low-side pull-down circuit.

## 12. Current Pre-PCB Pin Map

Current validated development wiring:

```text
ESP32-C3 GPIO6  -> I2C SDA -> TMP117 SDA, MAX30102 SDA
ESP32-C3 GPIO7  -> I2C SCL -> TMP117 SCL, MAX30102 SCL
ESP32-C3 GPIO10 -> Buzzer signal
ESP32-C3 GPIO20 -> SIM7080G DevKit UTX
ESP32-C3 GPIO21 -> SIM7080G DevKit URX
ESP32-C3 GPIO5  -> SIM7080G DevKit PWRK (prepared, physical test pending)
Common GND      -> all modules
```

Current validated features:

- TMP117 temperature read
- MAX30102 red/IR read
- wear detection
- buzzer state feedback
- LTE AT command communication
- SKT network registration on `45005`
- packet attach
- manual SMS transmission
- GNSS coordinate query

Still required before PCB schematic freeze:

- PWRK GPIO physical test
- battery/power-path decision
- LTE peak-current supply test
- final antenna connector decision
- final SIM holder decision
- final enclosure-driven sensor placement decision

## 13. SIM7080G DevKit PWRK Follow-Up Test

Additional PWRK testing was performed after connecting the SIM7080G developer kit to an external USB power source through a micro-USB cable and keeping the PWRK line connected to ESP32-C3 GPIO5.

Observed:

- With the previous modem power-down state, the modem did not respond to AT commands.
- After external power was applied, the modem eventually became responsive again.
- LTE registration recovered:

```text
AT
OK
CPIN READY
CSQ 26,99
CEREG 0,1
COPS SKTelecom
CGATT 1
```

Firmware command added:

```text
PWRKHIGH [ms]
```

Test result:

- `PWRKHIGH 3000` drove GPIO5 HIGH for about 3 seconds.
- After the HIGH pulse, the modem later printed:

```text
NORMAL POWER DOWN
```

- After this event, AT commands returned no response.
- A second `PWRKHIGH 3000` from the powered-down state did not bring AT communication back within the observation window.

Interpretation:

- The developer kit PWRK behavior is not the same as a simple active-low push button on this board.
- GPIO5 HIGH pulsing appears capable of triggering modem power-down.
- MCU-driven modem power-on has not yet been confirmed.
- External power stability improved modem availability, so modem supply behavior must remain a pre-PCB design focus.

Current status:

- `MODEMOFF` / `AT+CPOWD=1`: confirmed to power down modem.
- `PWRKHIGH 3000`: confirmed to trigger power-down when modem is on.
- `MODEMPWR` LOW pulse: did not recover modem from power-down during the observed tests.
- `PWRKHIGH 3000` from powered-down state: did not recover modem during the observed tests.

Next check:

- Manually recover modem power using the developer kit method that previously worked.
- After recovery, identify whether the developer kit PWRK pin is intended as:
  - a direct modem PWRKEY signal,
  - an enable pin,
  - or a board-level power control input.
- Final PCB should not copy the developer kit PWRK behavior blindly; use the target SIM7080G module datasheet/reference circuit for the final PWRKEY interface.

Follow-up:

- The modem green LED was observed blinking even while the firmware status still showed `lte_reg=0`.
- After firmware re-upload/reset and UART probing, LTE UART communication recovered at `115200`.
- `LTEPROBE` was added to test multiple UART baud rates.

Observed:

```text
[lte-probe] trying baud=115200
[lte-probe] baud=115200 attempt=1 response=OK
[lte-probe] success baud=115200
CPIN READY
CSQ 25 to 26
CEREG 0,1
COPS SKTelecom
CGATT 1
```

Updated interpretation:

- The modem was alive when the green LED was blinking.
- The temporary no-response state was likely due to reset/timing/UART synchronization during the power-control experiments, not confirmed modem death.
- External power through the micro-USB cable improved modem stability.
- Continue treating PWRK behavior as development-kit-specific until verified against the target module reference circuit.

## 14. Manual Emergency-Format SMS Test

A manual emergency-format SMS test was performed using live sensor/GNSS readings.

Firmware command added:

```text
ALERTSMS <number>
```

Command behavior:

- Estimate heart rate from MAX30102 IR samples for about 20 seconds.
- Read TMP117 temperature.
- Enable GNSS and query `AT+CGNSINF`.
- Disable GNSS after coordinate acquisition.
- Build an emergency-format SMS message.
- Send exactly one SMS through the existing manual SMS path.

Observed measured values:

```text
HR:   48.0 bpm
TEMP: 33.17 C
LOC:  36.049999,127.330002
```

GNSS observation:

```text
AT+CGNSPWR=1
OK
AT+CGNSINF
+CGNSINF: 1,,,36.050000,127.330003,-19.819,,,1,,0.1,0.1,0.1,,,,191841.6,6000.0
OK
```

Message preview:

```text
SOS HELP REQUEST
HR: 48.0 bpm
TEMP: 33.17 C
LOC: 36.049999,127.330002
```

First send attempt:

- The first `ALERTSMS` attempt used a phone number string containing hyphens.
- `AT+CMGS` returned `ERROR` before the SMS prompt.
- Result:

```text
[sms] failed: no prompt
[alert] SMS result=failed
```

Second send attempt:

- The same measured values were sent with a digits-only phone number.
- Message body was converted to a compact single-line ASCII format:

```text
SOS HELP REQUEST | HR: 48.0 bpm | TEMP: 33.17 C | LOC: 36.049999,127.330002
```

Observed result:

```text
[sms] sending to 01000000000
>
+CMGS: 8
OK
[cmd] SMS result=success
```

Conclusion:

- Live sensor values and GNSS coordinates were successfully included in an emergency-format SMS.
- Phone numbers should be passed to `AT+CMGS` as digits only, without hyphens.
- The current heart-rate estimate is still a rough prototype calculation and should not be treated as medically validated.
- The emergency SMS workflow should keep manual/rate-limited safeguards until persistent duplicate-prevention is implemented.

## 15. Power Supply / UART Recovery Test

Date: 2026-07-10

Bench equipment available:

- Multimeter
- Bench power supply
- Oscilloscope

Battery voltage before testing:

```text
Li-Po open-circuit voltage: 3.991 V
```

SIM7080G board power header check:

- With the SIM7080G board powered through micro-USB, the header `VDD` pin measured about `5.022 V`.
- Therefore this board's exposed `VDD` header is treated as a 5 V board input/rail, not a direct Li-Po/VBAT input.
- Direct 3.7 to 4.2 V Li-Po input to this `VDD` pin is not treated as a valid final test for bare SIM7080G VBAT behavior.

Bench power supply test:

```text
PSU setting: 5.00 V
Current limit: initially 0.50 A, later increased to 1.00 A
Connection: PSU + -> SIM7080G VDD, PSU - -> SIM7080G GND
```

Observed:

- Red power LED turned on.
- Current initially stayed very low, around `0.005 A`.
- PWRK activation was required.
- On this developer board, applying voltage to PWRK rather than pulling it to GND was observed to trigger board power behavior.
- With PSU at 5 V and current limit at 1 A, current varied roughly around `0.02 A` to `0.05 A` while the green LED was blinking.

UART/GND issue:

- During the first PSU-powered attempts, the green LED blinked but UART returned no AT response.
- One SIM7080G-side GND point was not connected to the ESP32-side GND and was then connected.
- After correcting the GND/common reference and restoring the UART wiring, UART communication recovered.

Measured powered UART idle voltages:

```text
SIM7080G VDD -> GND: 4.993 V
SIM7080G UTX -> GND: 3.24 V
SIM7080G URX -> GND: 3.313 V
```

Working UART wiring after correction:

```text
SIM7080G UTX -> ESP GPIO20
SIM7080G URX -> ESP GPIO21
SIM7080G GND -> ESP GND
```

Recovered UART result:

```text
LTEPROBE:
baud 115200 attempt 2 response: AT / OK
success baud=115200
```

LTE result:

```text
AT -> OK
CPIN READY
CSQ 19 to 20
CEREG 0,1
COPS SKTelecom
CGATT 1
lte-status at=1 sim=1 reg=1 attach=1
```

GNSS result:

```text
AT+CGNSPWR=1 -> OK
AT+CGNSINF attempt 3:
+CGNSINF: 1,,,36.050000,127.330003,-19.819,,,1,,0.1,0.1,0.1,,,,191844.8,6000.0
[gnss] coordinate acquired
```

Conclusion:

- The SIM7080G developer board can run from a bench 5 V supply through the exposed `VDD/GND` header.
- Common GND between PSU/SIM7080G/ESP32 is mandatory for UART communication.
- UART idle voltages around 3.2 to 3.3 V are consistent with active 3.3 V TTL UART.
- LTE registration and GNSS coordinate acquisition were confirmed after the wiring/reference issue was corrected.
- The current developer board's exposed `VDD` should be treated as 5 V input, not as the final bare-module Li-Po VBAT node.

Follow-up with micro-USB removed:

- SIM7080G micro-USB power was removed.
- Bench PSU was re-enabled as the SIM7080G board supply through `VDD/GND`.
- All other signal wiring remained unchanged.

Observed:

```text
LTEPROBE:
baud 115200 attempt 2 response: AT / OK
success baud=115200

LTE:
CPIN READY
CSQ 19 to 21
CEREG 0,1
COPS SKTelecom
CGATT 1
lte-status at=1 sim=1 reg=1 attach=1

GNSS:
AT+CGNSPWR=1 -> OK
AT+CGNSINF attempt 3 -> coordinate acquired
coordinate: 36.050000,127.330003
```

Conclusion:

- With the corrected common GND and UART wiring, the SIM7080G developer board operated successfully from the bench PSU via `VDD/GND` without micro-USB power.
- LTE registration and GNSS coordinate acquisition both passed under this PSU-powered condition.

## 16. PSU-Powered GNSS + SMS Load Test

Date: 2026-07-10

Purpose:

- Confirm whether the SIM7080G developer board remains stable during GNSS acquisition and SMS transmission while powered from a bench PSU through the board `VDD/GND` header.
- Heart-rate measurement was skipped because the user could not keep a finger on the MAX30102 while simultaneously holding measurement probes.

Firmware command added:

```text
POWERTESTSMS <number>
```

Command behavior:

- Skip heart-rate measurement.
- Read temperature if available.
- Enable GNSS.
- Acquire coordinate through `AT+CGNSINF`.
- Disable GNSS.
- Re-check LTE readiness.
- Send SMS with `HR: N/A`, temperature, and location.

Power setup:

```text
SIM7080G micro-USB: disconnected
PSU + -> SIM7080G VDD
PSU - -> SIM7080G GND
ESP32 USB -> PC for serial/debug
ESP32 GND -> SIM7080G GND common
PSU setting: 5.00 V
Current limit: 1.00 A
```

First run:

```text
GNSS coordinate acquired
LTE readiness recovered after GNSS off
SMS response: +CMGS: 9 / OK
[powertest] SMS result=success
```

Second run, with multimeter observation:

```text
GNSS coordinate acquired
LOC: 36.049999,127.330002
CSQ: 18
CEREG: 0,1
COPS: SKTelecom
CGATT: 1
SMS response: +CMGS: 10 / OK
[powertest] SMS result=success
```

User confirmed:

```text
SMS received.
Lowest observed voltage during the test: about 4.85 V
```

Conclusion:

- PSU-powered 5 V input through the SIM7080G developer board `VDD/GND` header passed GNSS + SMS load testing.
- Observed minimum voltage of about 4.85 V is acceptable for this 5 V board input test.
- No ESP32 reset was observed during the successful power-test SMS runs.
- No SIM7080G UART failure was observed during the successful power-test SMS runs.
- This confirms the developer board can operate from a stable 5 V rail, but does not prove bare SIM7080G direct Li-Po/VBAT operation because the exposed board `VDD` was measured as a 5 V rail.

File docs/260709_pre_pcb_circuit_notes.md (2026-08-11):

# Pre-PCB Circuit Notes

Date: 2026-07-09

Project: Heat Risk Alert Wristband

Purpose: summarize the validated development wiring and remaining circuit decisions before schematic capture.

## 1. Current Development Board

MCU:

- Seeed XIAO ESP32-C3

Firmware workspace:

```text
C:\Users\sukhe\Desktop\GCDP_codex_temp\firmware
```

Document/log workspace:

```text
N:\Own\01_YU\프로젝트 및 활동\2025-2_GCDP(Thailand-Korea)\GCDP_하계(Korea)\project
```

## 2. Validated Pin Map

```text
ESP32-C3 GPIO6  -> I2C SDA -> TMP117 SDA, MAX30102 SDA
ESP32-C3 GPIO7  -> I2C SCL -> TMP117 SCL, MAX30102 SCL
ESP32-C3 GPIO10 -> Buzzer signal
ESP32-C3 GPIO20 -> SIM7080G DevKit UTX
ESP32-C3 GPIO21 -> SIM7080G DevKit URX
ESP32-C3 GPIO5  -> SIM7080G DevKit PWRK (firmware prepared, physical test pending)
Common GND      -> all modules
```

Notes:

- TMP117 and MAX30102 share the same I2C bus.
- TMP117 address observed: `0x48`.
- MAX30102 address observed: `0x57`.
- SIM7080G UART baud rate used: `115200`.

## 3. Validated Functions

Confirmed during bring-up:

- ESP32-C3 firmware build/upload
- TMP117 temperature read
- MAX30102 red/IR read
- wear detection using MAX30102 IR threshold
- buzzer output on GPIO10
- SIM7080G AT command communication
- SKT registration through operator `45005`
- packet attach
- manual SMS transmission
- GNSS coordinate query through `AT+CGNSINF`

Current firmware commands:

```text
HELP
STATUS
LTE
GNSS
GNSSOFF
MODEMPWR
ALARM
CANCEL
SMS <number> <message>
```

Safety note:

- SMS is manual-only in the current firmware.
- Do not add automatic SMS sending until the emergency workflow and rate limiting are intentionally implemented.

## 4. SIM7080G Circuit Requirements

Required signals:

```text
UART TX/RX
PWRK
GND
Main power input
LTE antenna
GNSS antenna if location is used
SIM card interface or SIM holder
```

PWRK recommendation:

- Use an open-drain style low-side pull-down circuit for PWRK.
- MCU should pull PWRK LOW for about 1.8 to 2.0 seconds to toggle modem power.
- Avoid a final PCB design that forces a push-pull high level directly into PWRK.

Power recommendation:

- SIM7080G power must tolerate LTE current spikes.
- Add bulk capacitance close to the modem power input.
- Keep modem power traces short and wide.
- Verify whether the selected module requires direct Li-ion input, regulated 5 V, or regulated 3.8 to 4.2 V before schematic freeze.

## 5. Sensor Circuit Requirements

I2C bus:

- SDA: GPIO6
- SCL: GPIO7
- Confirm pull-up placement and values on the final PCB.
- Avoid duplicate overly-strong pull-ups if breakout modules already include pull-ups during prototype testing.

TMP117:

- VIN/GND/SDA/SCL required.
- INT and ADDR are currently unused.
- ADDR can remain default if address `0x48` is acceptable.

MAX30102:

- VIN/GND/SDA/SCL required.
- INT is currently unused.
- Final physical placement matters because optical contact quality affects wear detection.

## 6. Buzzer Circuit Requirements

Current prototype:

```text
ESP32-C3 GPIO10 -> buzzer signal
```

Final PCB decision:

- If using an active buzzer with low current, direct GPIO drive may be possible.
- If current is above safe GPIO limits, add a transistor driver and flyback/protection as appropriate.
- Decide final sound level based on wearable use, not just bench visibility.

## 7. Remaining Tests Before Schematic Freeze

Required:

- Connect `SIM7080G DevKit PWRK` to `ESP32-C3 GPIO5` and test `MODEMPWR`.
- Confirm modem starts from a fully off state using MCU PWRK control.
- Confirm LTE registration after MCU-driven modem power-up.
- Retest GNSS outdoors or near a window.
- Test operation from intended battery/power source.
- Measure or at least observe brownout/reset risk during LTE attach/SMS/GNSS.

Strongly recommended:

- Decide final SIM7080G form factor: developer kit is too large for final wearable; use a smaller module or custom carrier in PCB.
- Decide antenna connector/antenna type.
- Decide SIM holder location and accessibility.
- Decide charging path and power switch behavior.
- Decide enclosure and sensor window/contact geometry before finalizing MAX30102 placement.

## 8. Current PCB Readiness Status

Ready for schematic drafting:

- MCU pin allocation draft
- I2C sensor bus
- UART modem interface
- buzzer output
- manual SMS and GNSS firmware proof

Not ready to freeze:

- modem power rail
- PWRK hardware interface
- battery/charging circuit
- antenna mechanical placement
- final module footprint
- optical sensor mechanical placement

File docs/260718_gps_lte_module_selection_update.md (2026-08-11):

# 260718 GPS / LTE Module Selection Update

Date: 2026-07-18  
Purpose: Record the updated module decision before continuing PCB and case design.

## 1. Decision Summary

The previous SIM7080G developer-board based approach is no longer the intended final prototype direction because the module/devkit size is too large for the wearable form factor.

Updated direction:

```text
GPS:
  Use Beitian BE-220 GPS module.

LTE:
  Use a smaller Cat-M LTE module instead of the large SIM7080G developer board.

Previous SIM7080G developer board:
  Do not use for the wearable prototype enclosure.
  Keep only as a proven test/reference platform for AT command, LTE, GNSS, and SMS behavior.
```

Note: the earlier SIM7080G tests are still valuable because they verified the alert pipeline:

```text
Sensor read -> location acquisition -> SMS alert transmission
```

However, the mechanical design target now changes from one large LTE/GNSS devkit to separated smaller GPS and LTE modules.

## 2. New GPS Module: Beitian BE-220

Reference material saved in:

```text
C:\Users\sukhe\Desktop\GCDP_codex_temp\03_references\260718_BE-220
```

Reference files:

```text
260718_BE-220_datasheet.pdf
260718_BE-220_datasheet_cover.jpg
260718_BE-220_dimensions.jpg
260718_BE-220_overview.png
260718_BE-220_overview_product_parameter.jpg
260718_BE-220_pinout_led.jpg
260718_BE-220_specs.jpg
```

### BE-220 Main Specs

```text
Model: Beitian BE-220
Function: GPS module
Chip: M10050
Size: 22 mm x 20 mm x 6 mm
Weight: 5.3 g
Connector: 1.00 mm 4-pin connector
Supply voltage: DC 3.6 V to 5.5 V, typical 5.0 V
Current: about 15 mA at 5.0 V
Operating temperature: -40 C to +85 C
Storage temperature: -40 C to +105 C
```

### GNSS Support

```text
Default positioning system:
  GPS, BDS, GALILEO

Receiver type:
  GPS L1 C/A
  QZSS L1 C/A/S
  BDS B1I/B1C
  Galileo E1B/C
  SBAS L1 C/A: WAAS, EGNOS, MSAS, GAGAN

Augmentation:
  SBAS, QZSS
```

### Sensitivity / Accuracy

```text
Tracking and navigation: -166 dBm
Reacquisition: -160 dBm
Cold start: -148 dBm
Hot start: -160 dBm

Horizontal position accuracy: 2.0 m CEP
Velocity accuracy: 0.05 m/s
Dynamic heading: 0.3 deg
Time pulse: RMS 30 ns, 99% 60 ns
```

### Acquisition

```text
Cold start: 27 s
Hot start: 1 s
Aided start: 1 s
```

### Data Output

```text
Baud rate:
  4800 bps to 921600 bps
  Default 38400 bps

Electrical level:
  TTL level

Protocol:
  NMEA, UBX

NMEA messages:
  RMC, VTG, GGA, GSA, GSV, GLL

Update rate:
  0.25 Hz to 18 Hz
  Default 1 Hz

FLASH:
  Configuration can be changed and retained after power off.
```

### Pinout

```text
Pin 1: GND - Ground
Pin 2: TX  - Serial data output
Pin 3: RX  - Serial data input
Pin 4: VCC - DC 3.6 V to 5.5 V supply input, typical 5.0 V
```

### LEDs

```text
TX LED:
  Blue.
  Flashes when data output is present.

PPS LED:
  Red.
  Not bright when GPS is not fixed.
  Flashes after 3D positioning is achieved.
```

## 3. Impact on Architecture

Previous approach:

```text
SIM7080G developer board handled LTE + GNSS.
```

Updated approach:

```text
GPS location:
  BE-220 GPS module via UART.

LTE/SMS:
  Separate smaller Cat-M LTE module.

MCU:
  ESP32-C3 SuperMini remains the first-prototype controller unless changed later.
```

This means the ESP32-C3 now has to manage at least two serial devices:

```text
UART path 1:
  LTE Cat-M module for AT commands and SMS.

UART path 2:
  BE-220 GPS module for NMEA/UBX location data.
```

ESP32-C3 SuperMini pin pressure increases because it also needs:

```text
I2C SDA/SCL for TMP117 and MAX30102
Buzzer pin
LTE PWRK/control pin
Standalone trigger pin
LTE UART RX/TX
GPS UART RX/TX
```

Design implication:

- The next schematic must reserve a second UART path for GPS.
- If hardware UART availability or pin count becomes tight, GPS can be read through a software serial style approach only if reliable at the selected baud rate.
- Since BE-220 default is 38400 bps, it is more forgiving than very high-speed serial, but hardware UART is still preferable.

## 4. Firmware Impact

Existing firmware assumptions:

```text
GNSS location came from SIM7080G AT commands.
Commands used SIM7080G GNSS functions.
```

Required firmware change:

```text
Remove dependency on SIM7080G GNSS commands for final prototype.
Add BE-220 GPS serial parser.
Parse NMEA sentences, probably GGA/RMC first.
Keep LTE module focused on network registration and SMS.
```

Recommended first GPS firmware target:

```text
Read serial at BE-220 default 38400 bps.
Detect NMEA lines.
Parse GGA or RMC.
Extract:
  latitude
  longitude
  fix validity
  satellite/fix quality if available
Use last valid fix in alert SMS.
```

Alert SMS target format remains:

```text
HR: <bpm>, TEMP: <temperature>, LOC: <latitude>, <longitude>
```

## 5. PCB Design Impact

The first PCB should no longer be centered around the large SIM7080G developer board.

New PCB concerns:

```text
Add BE-220 4-pin connector footprint:
  GND
  TX
  RX
  VCC

Provide GPS power:
  3.6 V to 5.5 V allowed
  Typical 5 V
  About 15 mA

Route GPS UART to ESP32-C3.

Reserve separate LTE UART.

Keep GPS antenna ceramic patch clear of copper, battery, and metal nearby where possible.
```

Mechanical footprint:

```text
BE-220 module body: 22 mm x 20 mm x 6 mm
```

The GPS module is smaller than the earlier SIM7080G devkit but still has a ceramic patch antenna. Its top face orientation and keepout matter.

## 6. Case Design Impact

The case design should now treat GPS and LTE as separate RF blocks.

### GPS Placement

Recommended:

```text
Place BE-220 near the outer/top surface of the case.
Keep ceramic patch facing outward/upward.
Avoid placing battery directly over the patch antenna.
Avoid metal screws or dense copper immediately above/around the patch.
Do not bury it under thick or conductive material.
```

Reason:

- GPS reception is sensitive to antenna orientation and obstruction.
- The BE-220 includes a patch-style antenna area, so its physical orientation is part of the electrical design.

### LTE Placement

Recommended:

```text
Place LTE Cat-M module away from TMP117.
Keep LTE antenna path away from the body side where possible.
Provide RF cable or antenna clearance depending on selected LTE module.
```

Reason:

- LTE transmission can create heat and current spikes.
- LTE antenna performance can degrade if blocked by battery, skin, or metal.

### Sensor Placement Still Has Priority

The mechanical priorities remain:

```text
MAX30102:
  Must be flush to skin with light blocking.

TMP117:
  Must be near skin but thermally separated from LTE heat.

Battery:
  Must be mechanically protected.

GPS:
  Must face outward and be kept clear.

LTE:
  Must have antenna clearance and heat separation.
```

## 7. What Changes From the 260713 Team Document

The 260713 document described a working prototype using a SIM7080G LTE/GNSS path.

Updated interpretation:

```text
Keep:
  Sensor validation results.
  Battery test results.
  SMS alert workflow.
  ESP32-C3 SuperMini first-prototype controller assumption.
  Case requirements for MAX30102, TMP117, battery, buzzer, trigger, and debug access.

Change:
  Do not use the large SIM7080G devkit as the wearable communication/GNSS module.
  Split GPS and LTE into separate smaller modules.
  Add BE-220 GPS as the selected GPS module.
  Select/use a smaller Cat-M LTE module for SMS.
```

## 8. Immediate Next Steps

Hardware:

- Confirm the exact Cat-M LTE module model and pinout.
- Confirm BE-220 connector orientation and cable availability.
- Decide GPS UART pins on ESP32-C3 SuperMini.
- Decide LTE UART pins on ESP32-C3 SuperMini.

Firmware:

- Add BE-220 NMEA serial read test.
- Verify GPS fix and NMEA parse.
- Modify alert SMS to use BE-220 location.
- Keep LTE SMS sending independent from GPS parsing.

Case:

- Update block layout with BE-220 22 mm x 20 mm x 6 mm module.
- Put GPS on outer/top side.
- Keep MAX30102 and TMP117 on skin-facing side.
- Avoid placing BE-220 under battery or LTE module.

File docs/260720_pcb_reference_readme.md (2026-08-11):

# GCDP HRA Wristband Prototype

Current status as of 2026-07-20: this folder is no longer the main PCB design source. The active prototype direction is a wired wearable using fixed modules.

## Current Prototype Direction

```text
ESP32-C3 SuperMini
  + M5Stack Stamp CatM S003 LTE/SMS module
  + Beitian BE-220 GPS module
  + TMP117 module
  + MAX30102 module
  + active buzzer
  + TW-602035 Li-Po battery
  + TPU printed wristband/holder
```

## Fixed Components

See:

```text
C:\Users\sukhe\Desktop\GCDP_codex_temp\01_docs\260720_fixed_parts.md
C:\Users\sukhe\Desktop\GCDP_codex_temp\01_docs\260720_fixed_parts_and_architecture.md
```

## Notes

- Keep this folder only as a reference for previous PCB planning.
- Do not treat old RevA PCB notes as the current build plan unless they match the fixed parts document.
- The large SIM7080G developer board remains a validation/reference platform only.
- BE-220 is now the selected GPS module.
- LTE/SMS is handled by the small Cat-M module.
- The case must prioritize sensor skin contact, GPS outward placement, LTE antenna clearance, and wire strain relief.

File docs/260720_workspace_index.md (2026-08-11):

# Workspace Index

Updated: 260720

## Start Here

- `C:\Users\sukhe\Desktop\GCDP_codex_temp\260720_README.md`
- `C:\Users\sukhe\Desktop\GCDP_codex_temp\01_docs\260720_fixed_parts_and_architecture.md`
- `C:\Users\sukhe\Desktop\GCDP_codex_temp\01_docs\260720_fixed_parts.md`

## Main Folders

- `01_docs`: design records, fixed parts, preserved logs.
- `02_firmware`: current PlatformIO firmware.
- `03_references`: datasheets and module reference images.
- `04_media`: case/prototype photos and test media.

## Preserved Logs

- `260708_hardware_bringup_log.md`
- `260709_lte_sms_integrated_firmware_log.md`
- `260713_battery_standalone_alert_test_log.md`

## Fixed Parts

- MCU: ESP32-C3 SuperMini
- LTE/SMS: M5Stack Stamp CatM S003
- GPS/GNSS: Beitian BE-220
- Sensors: TMP117, MAX30102
- Alert: 3 V active buzzer
- Battery: TW-602035 Li-Po, 3.7 V, 380 mAh
- Case direction: TPU printed holder/band first

## Notes

- Team-notification drafts were removed from the active workspace.
- Exact duplicate images were removed after hash check.
- Historical handoff files may still mention older N-drive paths as part of their original context.

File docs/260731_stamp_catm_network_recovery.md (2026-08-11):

# 2026-07-31 Stamp CatM Network Recovery

## Purpose

Resolve the M5Stack Stamp CatM registration failure after UART, power, SIM
detection, antenna reception, and operator scanning had already passed.

## Reference Findings

The Korean Cat-M1 registration note at:

```text
https://ilikethisplus.tistory.com/65
```

distinguishes the general SKT LTE PLMN `45005` from the SKT Cat-M1 PLMN
`45012`. It also notes that `CPIN READY` alone does not prove that a line is
currently provisioned and that `CEREG stat 3` means registration denied.

Other SIM7080 and Stamp CatM reports consistently identify these checks:

```text
UART: 115200 baud, 8N1
LTE-only mode: AT+CNMP=38
Cat-M-only preference: AT+CMNB=1
Korean Cat-M bands: B1/B3/B5 are relevant; Korean examples also use B8
Clear stored registration/RPLMN data after a SIM or network change
Verify PDP/APN configuration before data activation
```

M5Stack Stamp CatM users also reported that correct UART pin mapping and a
stable 5 V supply are prerequisites. Both had already been verified on this
device.

## Live Baseline Readback

The Stamp was queried through ESP32-C3 USB serial on COM7.

```text
AT: OK
CFUN: 1
CNMP: 2
CMNB: 1
Cat-M bands: all module-supported bands
Carrier profile: automatic selection, Default active
CSDP: 2
Cell lock: disabled
COPS: automatic
CEREG: 0,2
CPSI: NO SERVICE
CGATT: 0
PDP context 1: IP, APN "YourAPN"
PDP context 2: IPV4V6, APN "ims"
```

Two local configuration discrepancies were found:

1. The live Stamp value was `CNMP=2` automatic, not the previously recorded
   `CNMP=38` LTE-only value.
2. PDP context 1 contained the literal example placeholder `YourAPN`.

## Recovery Commands

RF was stopped before clearing saved registration information.

```text
AT+CFUN=0
AT+CNMP=38
AT+CMNB=1
AT+CBANDCFG="CAT-M",1,3,5
AT+CGDCONT=1,"IP",""
AT+CLRNET=1,1
AT+CMCFG=1
AT+CFUN=1,1
```

Notes:

- `AT+CGDCONT=1` alone returned `ERROR`; explicitly setting an empty APN
  returned `OK`.
- PDP context 2, `ims`, was not modified.
- `AT+CLRNET=1,1` cleared Cat-M registration information and the last
  registered PLMN radio-access technology.
- The sequence did not erase the SIM, ICCID, IMSI, IMEI, or SMS records.

## Result

After modem reboot and automatic network search:

```text
AT+CPIN?: READY
AT+CNMP?: 38
AT+CMNB?: 1
AT+CBANDCFG?: CAT-M B1/B3/B5
AT+COPS?: automatic, SKTelecom, LTE-M access technology
AT+CEREG?: 0,1
AT+CPSI?: LTE CAT-M1, Online, 450-05, EUTRAN Band 5
AT+CGATT?: 1
AT+CSQ: 24,99
```

Final verdict:

```text
Stamp hardware: PASS
SIM detection: PASS
SKT Cat-M registration: PASS
Packet attachment: PASS
Korean network compatibility: CONFIRMED
Carrier intervention: NOT REQUIRED FOR THIS RECOVERY
SMS transmission: PASS
```

Because several stored settings were corrected as one controlled recovery
sequence, this test does not isolate one single command as the sole cause. The
combined local configuration cleanup resolved the failure without changing the
SIM, antenna, power source, UART wiring, or carrier account.

## Firmware Action

The verified initialization policy should be implemented in firmware:

```text
Set CNMP=38
Set CMNB=1
Use Cat-M bands B1/B3/B5 for the Korean prototype
Do not ship with placeholder APN "YourAPN"
Use the actual provider APN only when packet data is required
Do not run CLRNET on every boot; reserve it for recovery or SIM changes
```

The firmware was updated to apply the non-destructive settings on LTE
initialization and before the standalone alert registration step:

```text
AT+CNMP=38
AT+CMNB=1
AT+CBANDCFG="CAT-M",1,3,5
```

`CLRNET` and APN changes were intentionally not added to every boot.

Verification:

```text
PlatformIO environment: esp32c3_supermini
Build: PASS
Upload through COM7: PASS
Post-upload LTE status:
  SIM READY
  CEREG 0,1
  COPS SKTelecom, AcT 7
  CGATT 1
  CPSI LTE CAT-M1, Online, 450-05, Band 5
  CSQ 22 to 25
```
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

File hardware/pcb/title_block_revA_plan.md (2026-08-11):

# Altium Title Block RevA Plan

## Recommended Logo Assets

Use this as the main logo in the title block:

`C:\Users\sukhe\Desktop\GCDP_codex_temp\05_pcb_altium\branding\yeungnam_university_ui\altium_title_block_assets\yu_logo_horizontal_en_altium_600w.png`

Optional small seal:

`C:\Users\sukhe\Desktop\GCDP_codex_temp\05_pcb_altium\branding\yeungnam_university_ui\altium_title_block_assets\yu_seal_round_altium_240w.png`
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

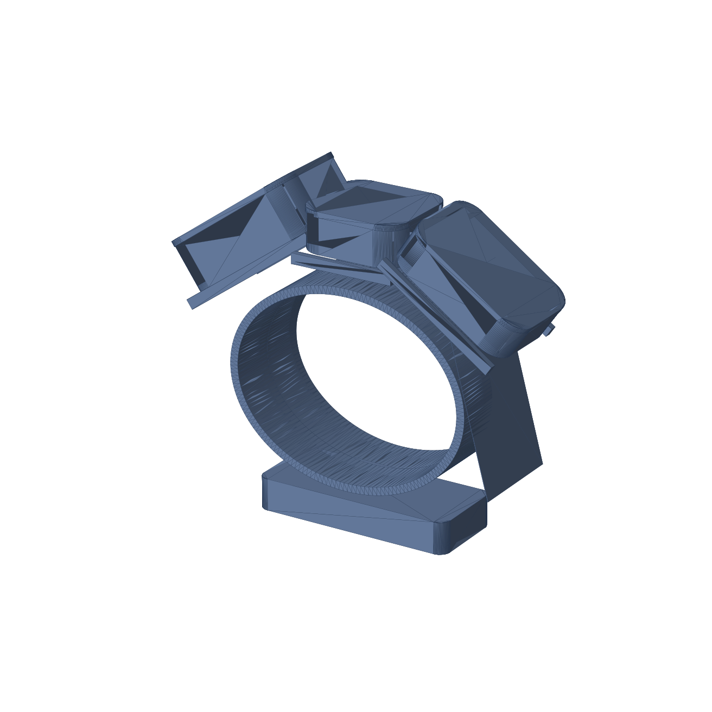
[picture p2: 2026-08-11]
hardware/enclosure/260802_parametric_wearable_v01/260802_layout_3pod_v01_preview.png

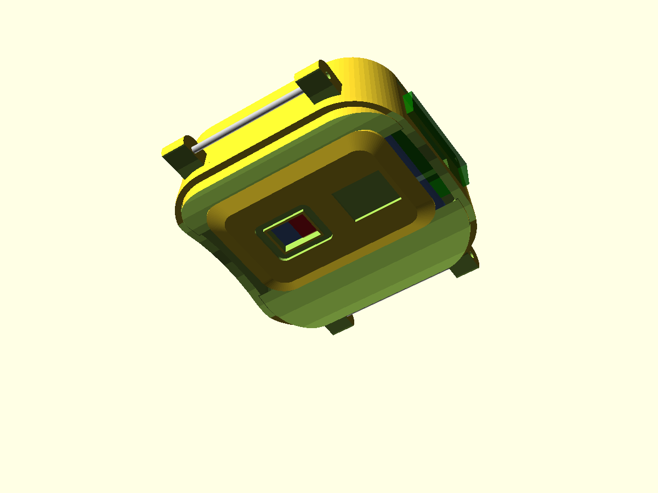
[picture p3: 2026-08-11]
hardware/enclosure/260728_case_designs_proto+concept/concept_bottom.png

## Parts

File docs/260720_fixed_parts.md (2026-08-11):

# GCDP Fixed Parts - 2026-07-20

This is the local temp copy of the current fixed component list. The main architecture note is:

```text
C:\Users\sukhe\Desktop\GCDP_codex_temp\01_docs\260720_fixed_parts_and_architecture.md
```

## Fixed Prototype Components

```text
MCU:
  ESP32-C3 SuperMini

LTE/SMS:
  M5Stack Stamp CatM S003
  Used for LTE registration and SMS only

GPS:
  Beitian BE-220 GPS/GNSS module
  VCC 3.6~5.5 V, typical 5 V
  UART default 38400 bps
  Pinout: GND / TX / RX / VCC

Sensors:
  TMP117 breakout/module, I2C 0x48
  MAX30102 breakout/module, I2C 0x57

Alert output:
  3 V active buzzer

Battery:
  TW-602035 Li-Po, 3.7 V, 380 mAh, 20 x 35 x 6 mm, 1.25 mm 2-pin

Trigger:
  GPIO4 active-low tactile switch or exposed pads

Case:
  TPU printed band/holder first
  Optional black silicone/foam only around MAX30102 light-blocking area
```

## SuperMini Pin Plan

```text
GPIO8  -> I2C SDA
GPIO9  -> I2C SCL
GPIO20 -> LTE UART RX
GPIO21 -> LTE UART TX
GPIO10 -> Buzzer
GPIO5  -> LTE PWRK/wake if needed
GPIO4  -> Standalone trigger to GND
GPIO6/GPIO7 or GPIO3/GPIO2 -> BE-220 GPS UART candidate
```

## BE-220 Quick Wiring

```text
Pin 1 GND -> ESP32 GND
Pin 2 TX  -> ESP32 GPS_RX
Pin 3 RX  -> ESP32 GPS_TX or NC for first read-only test
Pin 4 VCC -> 5 V preferred for first test
Baud      -> 38400
```

## Current Architecture

```text
TMP117/MAX30102 -> ESP32-C3 SuperMini via I2C
BE-220 GPS      -> ESP32-C3 SuperMini via GPS UART/NMEA
Cat-M module    -> ESP32-C3 SuperMini via LTE UART/AT commands
ESP32-C3        -> active buzzer and standalone trigger
Battery         -> powers prototype through tested power path
```

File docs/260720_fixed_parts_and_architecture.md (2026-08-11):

# 260720 Fixed Parts and Prototype Architecture

Date: 2026-07-20

Purpose: 현재 확정된 사용 부품과 프로토타입 구조를 기록한다. 팀원 노티용 문서는 제거하고, 기록용 로그는 보존한다.

## 1. Current Direction

현재 방향은 PCB-first가 아니라 배선형 wearable prototype이다.

```text
ESP32-C3 SuperMini
  + M5Stack Stamp CatM S003
  + Beitian BE-220 GPS module
  + TMP117 module
  + MAX30102 module
  + active buzzer
  + TW-602035 Li-Po battery
  + TPU/printed wristband enclosure
```

이전 SIM7080G large developer board는 최종 착용형 구조에 쓰지 않는다. 다만 LTE/SMS/GNSS/AT command 검증 기록으로는 보존한다.

## 2. Fixed Main Components

| Block | Fixed Part | Status | Notes |
| --- | --- | --- | --- |
| MCU | ESP32-C3 SuperMini | Fixed | Final prototype controller. USB-C remains accessible for upload/debug. |
| LTE/SMS | M5Stack Stamp CatM S003 | Fixed | Communication-only Cat-M. No GNSS by itself. UART 115200. MicroSIM/on-module SIM path. |
| GPS/GNSS | Beitian BE-220 GPS/GNSS module | Fixed | Separate GPS module via UART/NMEA. |
| Temperature | TMP117 breakout/module | Fixed | I2C address 0x48. Existing module retained. |
| Optical / wear | MAX30102 breakout/module | Fixed | I2C address 0x57. Existing module retained. |
| Alert output | 3 V active buzzer | Fixed | GPIO controlled. Existing buzzer class retained. |
| Battery | TW-602035 Li-Po 3.7 V 380 mAh | Fixed | 20 x 35 x 6 mm, 1.25 mm 2-pin connector. External charging only. |
| Trigger | Tactile switch or exposed pads | Fixed | Active-low standalone trigger to ESP32 GPIO4. |
| Enclosure | TPU printed band/holder first | Fixed direction | Silicone casting deferred unless needed for sensor contact pad. |

## 3. BE-220 GPS Module

Source folder:

```text
C:\Users\sukhe\Desktop\GCDP_codex_temp\03_references\260718_BE-220
```

Reference files:

```text
260718_BE-220_datasheet.pdf
260718_BE-220_datasheet_cover.jpg
260718_BE-220_dimensions.jpg
260718_BE-220_overview.png
260718_BE-220_overview_product_parameter.jpg
260718_BE-220_pinout_led.jpg
260718_BE-220_specs.jpg
```

Confirmed specs:

```text
Model: Beitian BE-220
Chip: M10050
Size: 22 x 20 x 6 mm
Weight: 5.3 g
Supply: DC 3.6 V to 5.5 V, typical 5.0 V
Current: about 15 mA at 5.0 V
Connector: 1.00 mm 4-pin
Default baud: 38400 bps
Protocol: NMEA, UBX
NMEA: RMC, VTG, GGA, GSA, GSV, GLL
Default update: 1 Hz
```

Pinout:

```text
Pin 1: GND
Pin 2: TX  serial data output
Pin 3: RX  serial data input
Pin 4: VCC 3.6 V to 5.5 V
```

Initial wiring:

```text
BE-220 GND -> ESP32 GND
BE-220 TX  -> ESP32 GPS_RX
BE-220 RX  -> ESP32 GPS_TX or NC for first read-only test
BE-220 VCC -> 5 V preferred for first test
Baud        38400
```

Case placement:

```text
Patch antenna face outward/upward.
Do not place battery over the patch antenna.
Keep away from LTE antenna/module as much as possible.
Avoid metal screws or dense copper above/around GPS.
```

## 4. LTE / Cat-M Module

Fixed direction:

```text
Use the small Cat-M module, not the large SIM7080G developer board.
Current selected module: M5Stack Stamp CatM S003.
```

Known module facts from saved notes:

```text
Based on SIM7080G.
Cat-M/NB-IoT communication.
No GNSS by itself.
UART: 115200 8N1.
MicroSIM on module.
LTE antenna via IPEX/SMA cable path.
Product size about 30.1 x 20.1 x 5.5 mm.
External connector includes TX, RX, GND, 3V3, 5V, ANT on reference drawing.
```

Design meaning:

```text
LTE handles network registration and SMS only.
GPS location comes from BE-220.
ESP32 must manage separate LTE UART and GPS UART.
```

## 5. ESP32-C3 SuperMini Pin Allocation

Final SuperMini target:

```text
GPIO8  -> I2C SDA for TMP117/MAX30102
GPIO9  -> I2C SCL for TMP117/MAX30102
GPIO20 -> LTE UART RX, ESP receives from Cat-M TX
GPIO21 -> LTE UART TX, ESP sends to Cat-M RX
GPIO10 -> Buzzer
GPIO5  -> LTE PWRK / module wake control if needed
GPIO4  -> Standalone trigger, active-low to GND
GPIO6/GPIO7 or GPIO3/GPIO2 -> GPS UART candidate, pending firmware test
```

Current firmware has both XIAO and SuperMini environments. PCB/case documentation should use SuperMini final pinout, while current bench test history may still mention XIAO pins.

## 6. Sensor Modules

TMP117:

```text
Use module/breakout, not bare IC.
VIN -> 3V3
GND -> GND
SDA/SCL -> shared I2C
INT/ADDR unused.
Address: 0x48
```

MAX30102:

```text
Use module/breakout, not bare IC.
VIN -> 3V3
GND -> GND
SDA/SCL -> shared I2C
INT/IRD/RD unused.
Address: 0x57
```

Mechanical note:

```text
MAX30102 must be flush to skin and light-blocked.
TMP117 must be near skin but separated from LTE heat.
Use strain relief on all soldered sensor wires.
```

## 7. Power

Battery:

```text
TW-602035 Li-Po
Nominal: 3.7 V
Capacity: 380 mAh
Energy: 1.406 Wh
Size: about 20 x 35 x 6 mm
Connector: 1.25 mm 2-pin
```

Confirmed from logs:

```text
Battery-powered prototype alert path: PASS.
ESP32-C3 external power with USB debug: PASS.
SIM7080G developer board battery-side power: PASS.
```

Current prototype policy:

```text
No onboard charger.
Charge battery externally.
Do not connect Li-Po directly to ESP32 3V3.
For the wired prototype, use the tested power path and keep grounds common.
```

If the selected Cat-M module requires 5 V, provide a suitable 5 V supply/boost path for that module. Do not assume every Cat-M board accepts raw Li-Po unless its exact input pin spec confirms it.

## 8. Buzzer and Trigger

Buzzer:

```text
3 V active DC buzzer
Operating range: about 2 V to 5 V
Rated current max: about 30 mA
ESP32 GPIO10 control
Use transistor/MOSFET driver if packaging allows; direct GPIO only for temporary bench tests.
```

Trigger:

```text
GPIO4 active-low to GND.
Hold low for about 1.5 s to start standalone alert flow.
Use tactile switch or exposed pads in the case.
```

## 9. Enclosure / Case

Fixed direction:

```text
TPU printed holder/band first.
Silicone casting is optional and deferred.
```

Recommended layout:

```text
Skin side:
  MAX30102 optical window
  TMP117 thermal contact area

Outer/top side:
  BE-220 GPS patch antenna facing outward
  LTE antenna with clearance

Main body:
  ESP32-C3 SuperMini
  Cat-M module
  battery
  buzzer
  trigger button/pads
  wire strain relief
```

## 10. Consumables / Tools

Recommended:

```text
A-888 leaded solder paste or normal solder wire + flux
RMA-223 flux
Heat shrink tube
Thin flexible wires
Kapton/electrical tape
Hot glue / UV resin / epoxy for strain relief
TPU filament
Optional black silicone or foam ring for MAX30102 light blocking
```

Not required:

```text
Buying every solder paste type.
Silicone full-body casting for the first wearable prototype.
PCB antenna.
Bare ESP32-C3 / bare SIM7080G module integration.
```

## 11. Preserved / Removed Documents

Preserve as logs:

```text
01_docs/260708_hardware_bringup_log.md
01_docs/260709_lte_sms_integrated_firmware_log.md
01_docs/260713_battery_standalone_alert_test_log.md
```

Removed as team-notice style document:

```text
removed: team notification draft, not a record log
```

Current authoritative design documents:

```text
01_docs/260718_gps_lte_module_selection_update.md
01_docs/260720_fixed_parts_and_architecture.md
```

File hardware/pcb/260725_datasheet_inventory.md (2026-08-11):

# Datasheet / PCB Reference Inventory - 2026-07-25

Purpose: local inventory of electrical and PCB reference documents for the GCDP heat-risk alert wristband.

## Datasheets

| Part | Local file | Status | Use |
| --- | --- | --- | --- |
| ESP32-C3 chip | `esp32_c3_chip_datasheet_en.pdf` | Stored | Chip-level electrical reference. Use for PCB design only if moving beyond SuperMini carrier. |
| M5Stack Stamp CatM S003 | `m5stack_stamp_catm_s003.pdf` | Stored | Stamp CatM module pinout/spec reference. Primary LTE module document for the current architecture. |
| SIM7080 series | `sim7080_series_spec_20200427.pdf` | Stored | SIM7080G chip/module electrical reference. Use for power, UART, SIM, RF, and PCB design decisions. |

## PCB References

| Part | Local file | Status | Use |
| --- | --- | --- | --- |
| Adafruit TMP117 PCB | `..\reference_pcbs\tmp117_adafruit\adafruit_tmp117_pcb_main.zip` | Stored | Official Adafruit PCB source archive. |
| Adafruit TMP117 PCB folder | `..\reference_pcbs\tmp117_adafruit\Adafruit-TMP117-PCB-main\Adafruit_TMP117.brd` | Moved from Downloads | Eagle board reference. |
| Adafruit TMP117 schematic folder | `..\reference_pcbs\tmp117_adafruit\Adafruit-TMP117-PCB-main\Adafruit_TMP117.sch` | Moved from Downloads | Eagle schematic reference. |

## Case / Mechanical Datasheets

These are stored under `06_3d_case/references/datasheets` because they are mostly useful for enclosure/blockout dimensions:

| Part | Local file | Use |
| --- | --- | --- |
| Adafruit TMP117 breakout | `..\..\06_3d_case\references\datasheets\adafruit_tmp117_high_accuracy_i2c_temperature_monitor.pdf` | Mechanical/pin reference for TMP117 breakout. |
| ESP32-C3 SuperMini board | `..\..\06_3d_case\references\datasheets\esp32_c3_supermini_board_datasheet.pdf` | Board-level mechanical/pin reference for SuperMini carrier. |

## Duplicate / Not Copied

| Source file | Reason |
| --- | --- |
| `C:\Users\sukhe\Downloads\Adafruit TMP117 (1).fzpz` | Duplicate of `Adafruit TMP117.fzpz` by SHA256 hash. Only one copy was stored. |

## Source Cleanup

The listed downloaded source files and folder were moved out of `C:\Users\sukhe\Downloads` into this workspace on 2026-07-25. The Downloads copies are no longer present.

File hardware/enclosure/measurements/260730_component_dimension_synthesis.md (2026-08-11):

# 260730 Component Dimension Synthesis

Date: 2026-07-30

Purpose: Establish the mechanical input dimensions for the camp wearable
prototype from saved datasheets, vendor drawings, and exact purchased-part
references.

The previous `proto_case` geometry is not a design input for this document.

## 0. Primary Local Sources

- `06_3d_case/references/datasheets/esp32_c3_supermini_board_datasheet.pdf`
- `05_pcb_altium/datasheets/m5stack_stamp_catm_s003.pdf`
- `03_references/260718_BE-220/260718_BE-220_dimensions.jpg`
- `03_references/260718_BE-220/260718_BE-220_datasheet.pdf`
- `03_references/260712_sensor_refs/260712_adafruit_sensor_ref_01.png`
- `04_media/260713_case_refs/260713_case_ref_03.png`
- `04_media/260713_case_refs/260713_case_ref_04.png`
- `04_media/260713_case_refs/260713_case_ref_05.png`
- `03_references/260730_batteries/260730_TW-402025_150mAh_specs.png`
- `03_references/260730_batteries/260730_TW-602025_220mAh_specs.jpg`

## 1. Dimension Status

| Part | Documented body size (mm) | Status | Mechanical notes |
| --- | ---: | --- | --- |
| ESP32-C3 SuperMini | 22.52 x 18.00 x 4.0 measured | Physical measurement confirmed | The bare PCB is less than 1 mm thick. The USB-C connector is the highest feature and extends less than 1 mm beyond the board edge. Use a fresh board without pin headers and solder thin flexible wires directly to the required pads. |
| M5Stack Stamp CatM S003 | 30.3 x 20.0 x 6.0 measured | Physical measurement confirmed | The SIM-holder region is the tallest point. Most of the remaining body is about 4 mm high. A thin removable plastic armor is installed. Keep the armor for the first camp prototype unless enclosure thickness becomes critical. |
| Beitian BE-220 GPS | 22.0 x 20.0 x 6.25 maximum measured | Physical measurement confirmed after delivery | The module body is effectively occupied by the receiver and ceramic antenna. Treat 6.0 mm as the nominal body height and 6.25 mm as the measured worst-case fit height. Ceramic patch faces outward. |
| Adafruit TMP117 breakout | 25.40 x 17.78 x 5.0 measured | Physical measurement confirmed | Maximum height includes the installed 4-pin connector. Without the connector, the tallest board feature is about 2.6 mm. The approximately 2 x 2 mm TMP117 chip is centered on the PCB. Keep the connector for the camp prototype because the 5 mm total height remains acceptable and serviceability is useful. |
| MAX30102 breakout currently used | 21 x 16 x 3.0 overall measured | Physical measurement confirmed | PCB thickness is about 1.2 mm. The optical package is about 6 x 3 mm and centered on the PCB. With PCB axes X=21 and Y=16, the optical package is X=3 and Y=6. Existing pin-header protrusion is not included in this body size. |
| TW-602035 380 mAh Li-Po | 35 x 20 x 6 measured | Tested, not selected | This battery powered repeated bench tests without recharge, but its 35 mm length is rejected for the wearable prototype. Retain as a bench-test battery. |
| TW-602025 220 mAh Li-Po | 28 x 20 x 6 measured | Selected and physically confirmed | Fixed wearable battery as of 2026-08-02. Physical measurement overrides the nominal 20 x 25 x 6 mm product listing. CAD convention is length 28, width 20, height 6 mm. Wire length is adjustable. |
| TW-402025 150 mAh Li-Po | 25 x 20 x 4 nominal | Alternate only | Its plan dimensions are effectively the same as the selected 220 mAh cell, while the capacity is lower. It is no longer the primary enclosure target. |
| 3 V active buzzer FQ-013 / TMB09A03 | 9.1 diameter x 5.9 body height measured | Physical measurement confirmed | Cylindrical body. Vendor drawing gives 5.6 mm lead spacing and about 6.0 +/- 0.5 mm lead length. Leads may be trimmed after soldering. |
| Start/debug trigger | No external button required | Architecture decision | Normal operation starts from stable MAX30102 wear/contact detection. Retain only an optional internal test pad or firmware debug trigger for forced execution during development. |
| Quectel YF0006AA LTE antenna | 50 x 25 x 0.13 antenna body; 30 mm cable | Official datasheet confirmed | The distributor screenshot says 50 x 20 mm, but Quectel V2.3 specifies 50 x 25 mm. Use the official larger width until the actual part is measured. U.FL termination; place on an outward-facing non-metallic surface, not beneath the battery or against skin. |

## 2. CAD Block Dimensions

These are the recommended first-pass CAD envelope values. They include small
body tolerance only, not cable bend space or general assembly clearance.

| Part | CAD body envelope (mm) |
| --- | ---: |
| ESP32-C3 SuperMini | 23.0 x 18.5 x 4.6 |
| Stamp CatM S003 | 30.9 x 20.6 x 6.6 |
| BE-220 GPS | 22.6 x 20.6 x 6.9 |
| TMP117 breakout | 26.0 x 18.4 x 5.6 |
| MAX30102 breakout | 21.6 x 16.6 x 3.5, excluding full pin-header protrusion |
| 380 mAh battery pocket (bench reference only) | 36 x 21 x 6.8 |
| 220 mAh battery pocket (selected, first pass) | 28.8 x 20.8 x 6.8 |
| 150 mAh battery pocket (alternate only) | 26 x 21 x 4.8 |
| Active buzzer | 9.7 diameter x 6.5, excluding full lead length |
| Optional internal test pad | PCB pad only; no enclosure press feature |
| LTE film antenna | 50 x 25 x 0.13, plus 30 mm coax routing envelope |

Do not add final print-fit clearance twice. The values above are component
envelopes; enclosure pocket clearance is added later according to the printer,
material, and retention method.

## 3. Required Physical Measurements

Measure in this order because each item can change the enclosure architecture.

1. Selected 220 mAh battery:
   confirm the first printed pocket fit and inspect protection-board bulge and
   wire-exit compression before the final retention feature is added.
2. LTE antenna:
   measure the actual film width to resolve the 20 mm distributor listing versus
   the 25 mm official Quectel datasheet value.

## 4. Mechanical Constraints Already Fixed

- MAX30102 optical face must contact skin and be surrounded by a light-blocking ring.
- TMP117 must be skin-adjacent and thermally separated from Stamp CatM and power heat.
- BE-220 ceramic patch must face outward with no battery or metal directly above it.
- The Li-Po pouch must not be compressed by the lid, screws, or wrist curvature.
- ESP32-C3 USB-C must remain accessible until firmware is stable.
- Every soldered wire exit needs strain relief.
- SIM access and the LTE antenna connection must remain serviceable for the camp prototype.
- Use the 220 mAh cell as the prototype packaging baseline. Complete a final
  battery-only end-to-end demonstration after the mechanical assembly is wired.

## 5. Wrist and Wearable Limits

Physical wearer measurements:

```text
Wrist circumference: 165 mm
Top straight width: 55 mm
Comfortable enclosure length along the wrist: 40 mm
Maximum enclosure width across the wrist: less than 50 mm
```

Working mechanical targets:

```text
Main electronics pod: no larger than 50 x 40 mm in plan
Strap width: 22 mm provisional
Reason for 22 mm: suitable for the compact sensor harness. The official 25 mm-wide
LTE film antenna may need to bridge the strap edges or occupy an enclosure surface.
```

## 6. Current Gate

Milestone M2 is complete only when every `physical measurement required` item
has a measured value or an explicit prototype allowance.

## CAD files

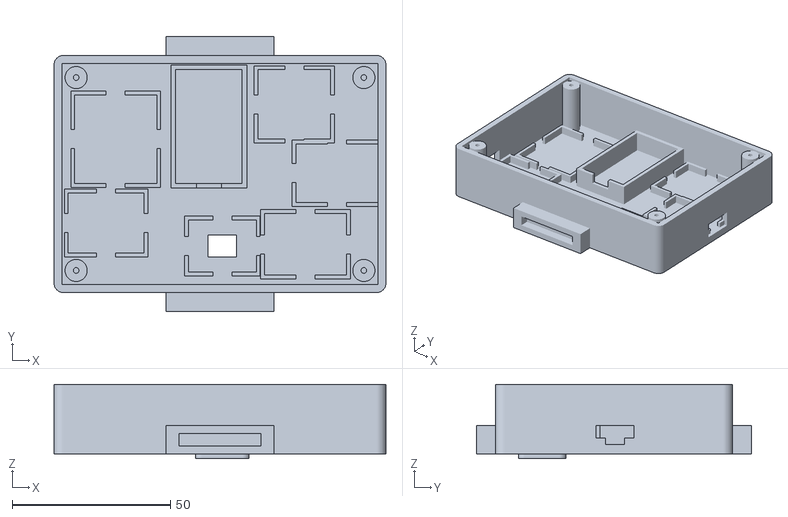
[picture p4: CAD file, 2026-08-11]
hardware/enclosure/260728_case_designs_proto+concept/proto_base.stl
105.0 x 87.0 x 23.5

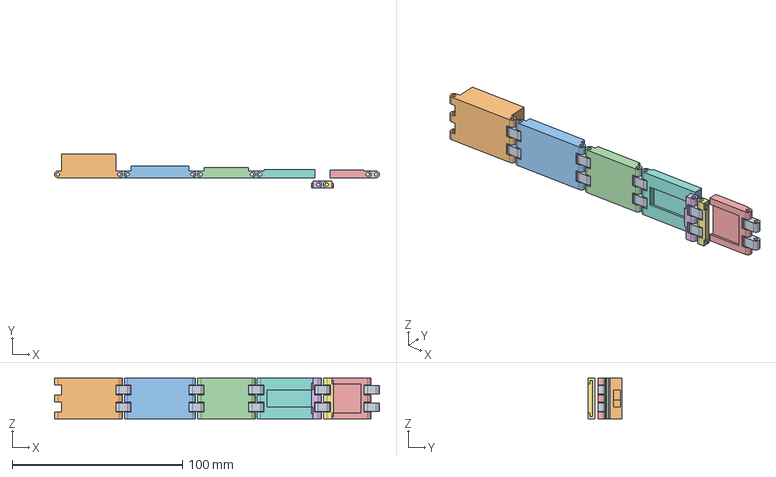
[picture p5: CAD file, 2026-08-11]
hardware/enclosure/260803_fusion_export/analysis/GCDP_design_1_review.step
191.0 x 20.0 x 24.0 mm

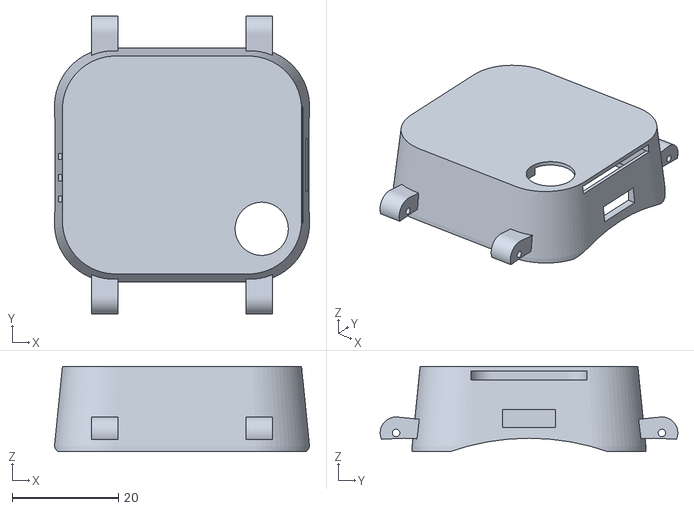
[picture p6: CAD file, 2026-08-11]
hardware/enclosure/260728_case_designs_proto+concept/concept_shell.stl
48.0 x 56.0 x 16.0

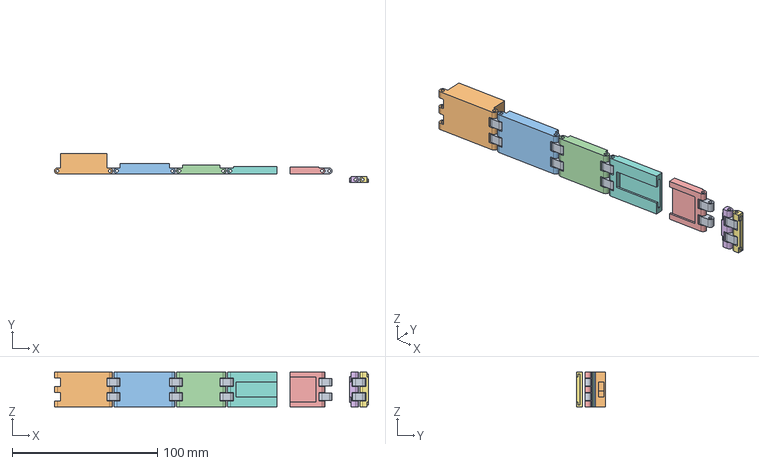
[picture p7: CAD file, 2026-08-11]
hardware/enclosure/260803_fusion_export/analysis/GCDP_design_1_current.step
216.0 x 20.0 x 24.0 mm

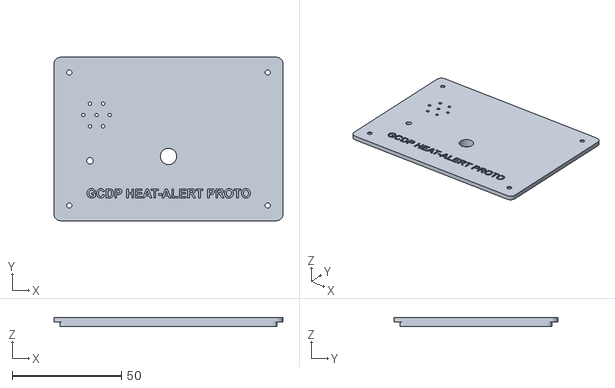
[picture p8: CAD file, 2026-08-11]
hardware/enclosure/260728_case_designs_proto+concept/proto_lid.stl
105.0 x 75.0 x 4.20

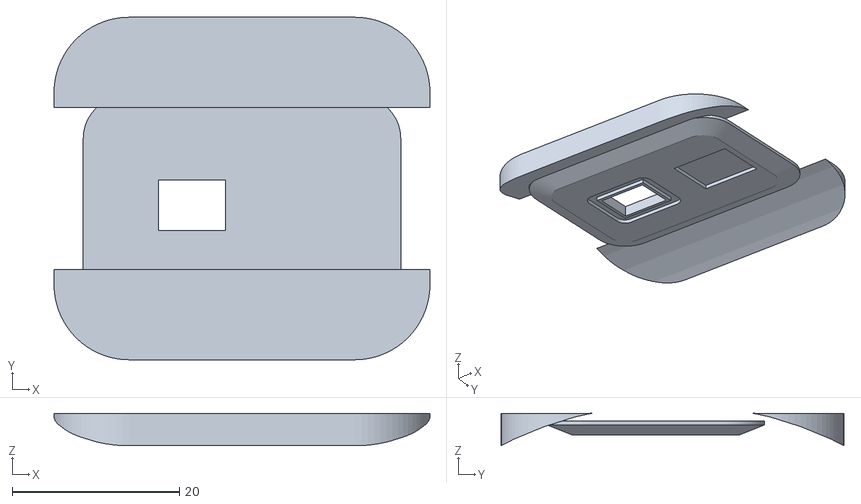
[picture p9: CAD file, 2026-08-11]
hardware/enclosure/260728_case_designs_proto+concept/concept_bottom.stl
45.0 x 41.0 x 3.89

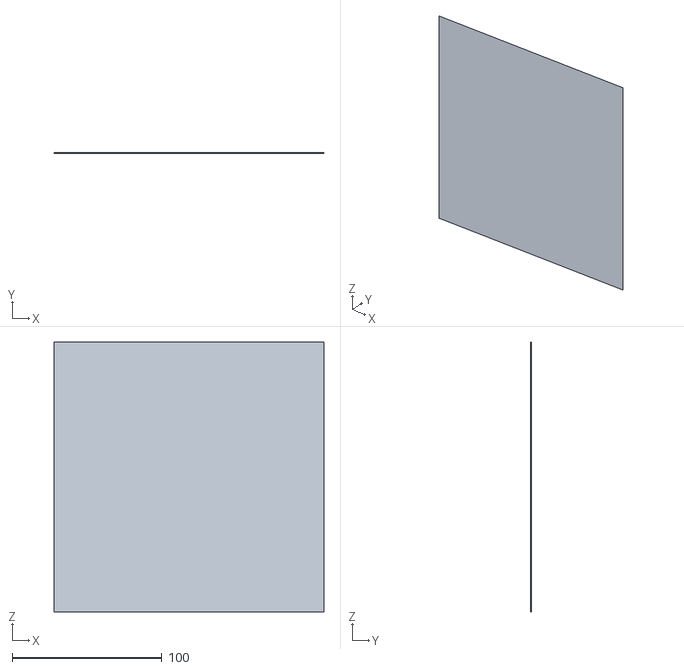
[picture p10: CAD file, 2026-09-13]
evidence/3d-printing/01_출력_증빙/260810_plate_level_test.stl
180.0 x 0.2 x 180.0

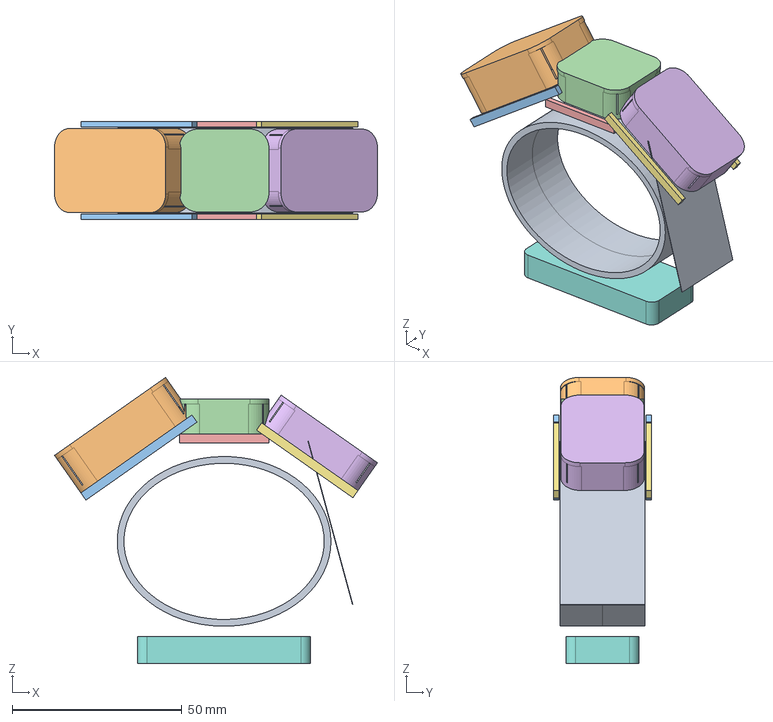
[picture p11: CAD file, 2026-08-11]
hardware/enclosure/260802_parametric_wearable_v01/exports/260802_layout_3pod_v01.step
95.2 x 28.8 x 84.3 mm

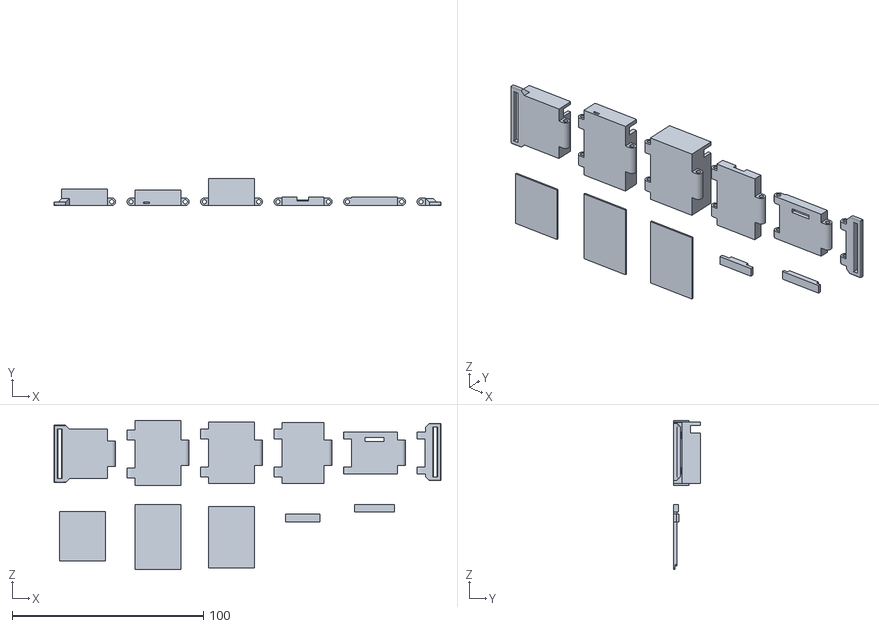
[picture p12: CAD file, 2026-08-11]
hardware/enclosure/current/260807_print_current.stl
202.3 x 14.2 x 78.0

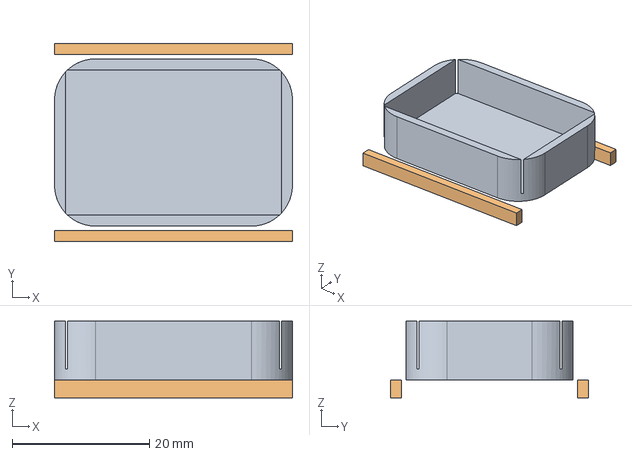
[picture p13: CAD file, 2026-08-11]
hardware/enclosure/260802_parametric_wearable_v01/exports/260802_stamp_catm_pod_base_v01.step
34.7 x 28.8 x 11.2 mm

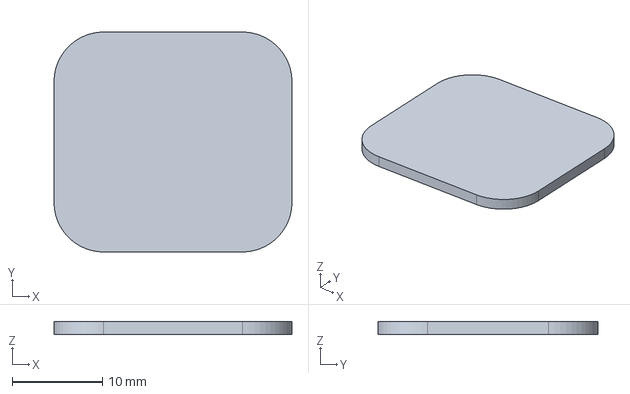
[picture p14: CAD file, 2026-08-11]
hardware/enclosure/260802_parametric_wearable_v01/exports/260802_gps_pod_lid_v01.step
26.4 x 24.4 x 1.40 mm

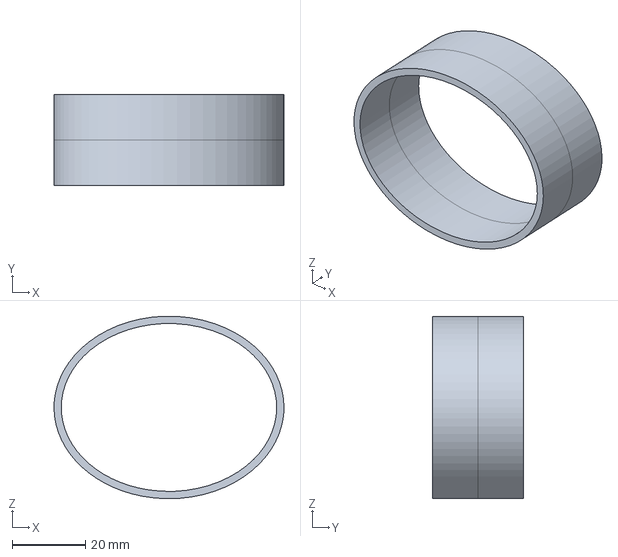
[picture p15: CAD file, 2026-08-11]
hardware/enclosure/260802_parametric_wearable_v01/exports/260802_wrist_165mm_strap_25mm_reference.step
63.0 x 25.0 x 50.0 mm

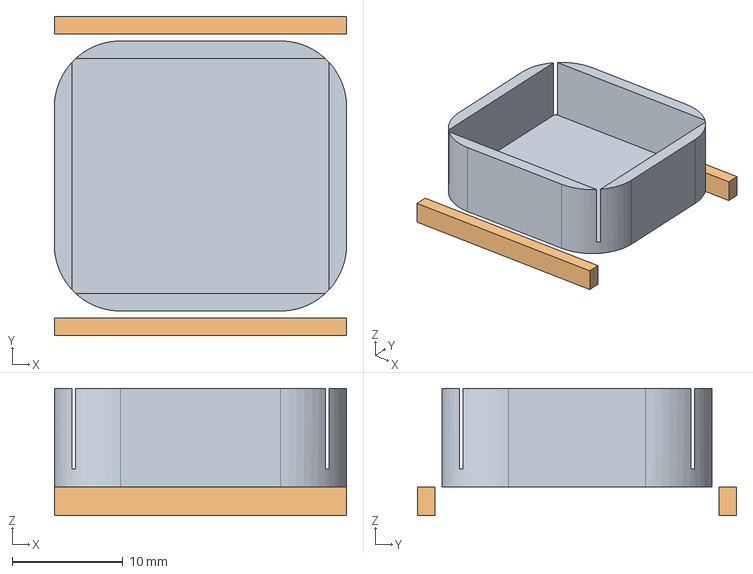
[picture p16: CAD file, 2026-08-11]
hardware/enclosure/260802_parametric_wearable_v01/exports/260802_gps_pod_base_v01.step
26.4 x 28.8 x 11.5 mm

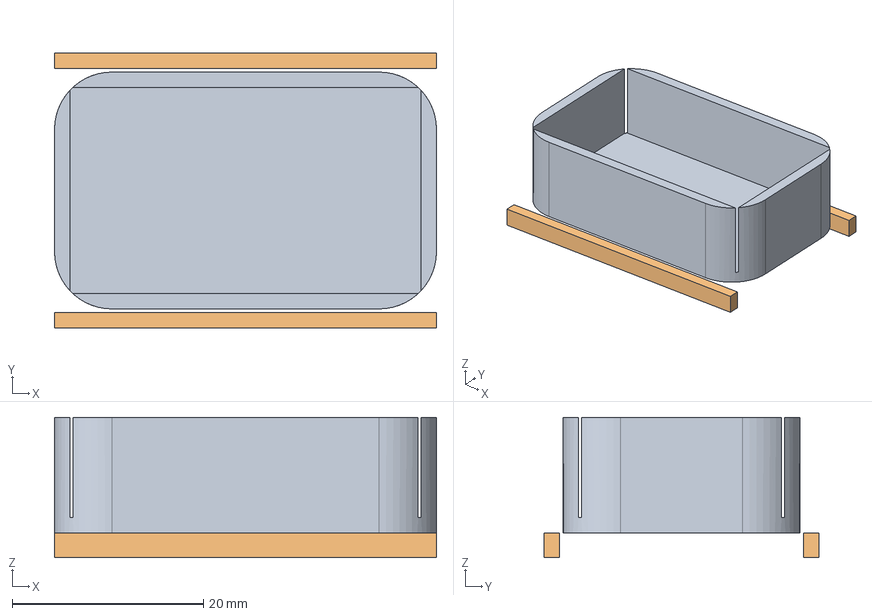
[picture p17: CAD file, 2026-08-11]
hardware/enclosure/260802_parametric_wearable_v01/exports/260802_battery_esp_pod_base_v01.step
40.0 x 28.8 x 14.7 mm

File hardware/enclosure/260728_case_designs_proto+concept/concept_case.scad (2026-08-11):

// ============================================================
// GCDP Heat Risk Alert Wristband — 컨셉 케이스 (이상적 최종 버전)
// 260713 문서 "Later final version" 방향: 통합 PCB 전제, 스마트워치 폼팩터
// 수직 스택: 피부면 센서 → 통합 PCB(ESP32+LTE) → 배터리 → GPS(최상층)
// 단위: mm  |  OpenSCAD에서 열기
// ============================================================

// ---------- 출력 선택 ----------
part = "assembly";      // "shell" | "bottom" | "assembly"
show_components = true; // 내부 스택 고스트
exploded = 0;           // 바닥 플레이트 분리 거리 (0 = 조립)

// ---------- 주요 파라미터 ----------
body_x  = 48;      // 팔 방향
body_y  = 44;      // 손목 둘레 방향
body_h  = 16;      // 전체 높이 (통합 설계 목표 14~17)
body_r  = 11;      // 모서리 라운드
wall    = 2.0;
bot_t   = 1.4;     // 바닥(센서) 플레이트 두께
wrist_R = 45;      // 손목 곡률 반경 (곡면 밑면)
band_w  = 24;      // 시계줄 폭
lug_gap = 3;       // 러그-밴드 간격

$fn = 72;

// ============================================================
// 유틸
// ============================================================
module rbody(x, y, z, r) {
    linear_extrude(z) offset(r=r) offset(delta=-r)
        square([x, y], center=true);
}
// 손목 곡면 절단용 실린더 (팔 방향 = X축)
module wrist_cut() {
    translate([0, 0, -wrist_R + 2.5])
        rotate([0, 90, 0]) cylinder(r=wrist_R, h=body_x+40, center=true);
}

// ============================================================
// 메인 쉘 (윗몸통) — 위에서 씌우는 구조
// ============================================================
module shell() {
    difference() {
        union() {
            // 몸통 (위로 갈수록 살짝 좁아지는 2단 프로파일)
            hull() {
                rbody(body_x, body_y, 1, body_r);
                translate([0,0,body_h-2]) rbody(body_x-3, body_y-3, 2, body_r-1);
            }
            // 러그 (±Y, 24mm 밴드)
            for (s = [1, -1]) lug(s);
        }
        // 손목 곡면 (밑면을 오목하게)
        wrist_cut();
        // 내부 공동 (상판 2.5 남김)
        translate([0, 0, bot_t])
            rbody(body_x-2*wall, body_y-2*wall, body_h-2.5-bot_t, body_r-wall);
        // 바닥 플레이트 안착 립
        translate([0, 0, -6])
            rbody(body_x-2*wall+1.2, body_y-2*wall+1.2, 6+bot_t+0.05, body_r-wall);
        // GPS 스카이라이트 (상판을 0.8mm만 남김 — 세라믹 패치 바로 위)
        translate([14, 0, body_h-2.5-0.01])
            rbody(24, 22, 2.5-0.8, 4);
        // 트리거 버튼 리세스 (오목하게 넣어 오작동 방지) + 관통
        translate([15, -12, body_h-3.5]) cylinder(d=10, h=5);
        translate([15, -12, body_h-8])   cylinder(d=6.2, h=8);
        // USB-C 포트 (+X 측면, 스트랩에 가려지지 않는 면)
        translate([body_x/2-wall-1, -5, 4.5]) cube([wall+2, 10, 3.4]);
        // 부저 마이크로 슬릿 (-X 측면 3줄)
        for (i = [-1:1])
            translate([-body_x/2-1, -3+i*4, 9]) cube([wall+2, 1.2, 6]);
    }
}
module lug(s) {
    // 일체형 러그 + 스프링바 구멍
    for (x = [-band_w/2-2.5, band_w/2+2.5])
        translate([x, s*(body_y/2+lug_gap/2), 0])
            difference() {
                hull() {
                    translate([0, -s*lug_gap, 2]) cube([5, 1, 8], center=true);
                    translate([0, s*1.5, 3.5]) rotate([0,90,0])
                        cylinder(d=6, h=5, center=true);
                }
                translate([0, s*1.5, 3.5]) rotate([90,0,90])
                    cylinder(d=1.4, h=7, center=true);
                wrist_cut();
            }
    // 스프링바 (표시용)
    if (show_components)
        translate([0, s*(body_y/2+lug_gap/2+1.5), 3.5])
            %color("silver") rotate([0,90,0]) cylinder(d=1.3, h=band_w+8, center=true);
}

// ============================================================
// 바닥 센서 플레이트 (피부 접촉면) — 스냅 삽입
// ============================================================
module bottom() {
    difference() {
        union() {
            // 곡면 따라가는 플레이트
            intersection() {
                translate([0,0,-10]) rbody(body_x-2*wall+1, body_y-2*wall+1, 10+bot_t, body_r-wall);
                difference() {
                    translate([0,0,-30]) rbody(body_x, body_y, 40, body_r);
                    wrist_cut();
                }
            }
            // 센서 포드 (중앙 1.2mm 돌출 → 피부 밀착 압력 집중)
            translate([0, -2, 0]) sensor_pod();
        }
        // MAX30102 광학 창 (8x6)
        translate([-6, -2, -12]) linear_extrude(15) square([8, 6], center=true);
        // TMP117 열섬 박막 (0.6mm)
        translate([10, -2, -12+0.01]) linear_extrude(12-0.6) square([10, 8], center=true);
    }
}
module sensor_pod() {
    difference() {
        hull() {
            translate([0,0,-1.2]) linear_extrude(0.5) offset(r=3) square([26, 14], center=true);
            linear_extrude(0.5) offset(r=5) square([28, 16], center=true);
        }
        // 광학 창 주변 차광 링 홈 (검정 실리콘/TPU 인서트 자리)
        translate([-6, 0, -1.3]) linear_extrude(0.7) difference() {
            offset(r=1.5) square([9, 7], center=true);
            square([9, 7], center=true);
        }
    }
}

// ============================================================
// 내부 스택 고스트 (이상적 통합 구성)
// ============================================================
module components() {
    if (show_components) {
        // 1층: 센서 (바닥 플레이트 위)
        %color("red", 0.6)    translate([-6, -4, 0.3])  cube([12, 12, 1.5], center=false);  // MAX30102 (PCB 직실장)
        %color("orange", 0.6) translate([6, -5, 0.3])   cube([6, 6, 1.2]);                  // TMP117 (베어칩)
        // 2층: 통합 메인 PCB (ESP32-C3 + LTE Cat-M 온보드)
        %color("royalblue", 0.55) translate([0, 0, 2.6])  rbody(38, 33, 1.6, 6);
        // 3층: 배터리(세로 배치)와 GPS를 PCB 위에 나란히
        %color("gray", 0.6)   translate([-19, -17.5, 4.4]) cube([20, 35, 6]);   // 배터리 380mAh
        %color("green", 0.6)  translate([3, -10, 4.4])     cube([22, 20, 6]);   // BE-220 GPS (스카이라이트 아래)
    }
}

if (part == "shell")  shell();
if (part == "bottom") bottom();
if (part == "assembly") {
    shell();
    translate([0, 0, -exploded]) bottom();
    components();
}

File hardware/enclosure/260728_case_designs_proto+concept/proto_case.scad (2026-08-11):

// ============================================================
// GCDP Heat Risk Alert Wristband — 프로토타입 케이스 (널널 버전 v2)
// 개발/디버깅 편의 최우선: 모든 모듈이 한 층에 나란히, 점퍼선 여유 확보
// v2: LTE 미확정 → 대형 예약 베이(26x28), 충전모듈(TP4056) 베이 추가
// 단위: mm  |  OpenSCAD (openscad.org)에서 열기
//
// 부품 근거 (260713 / 260718 문서):
//   ESP32-C3 SuperMini 22.5x18   | BE-220 GPS 22x20x6 (안테나 위)
//   배터리 TW-602035 20x35x6      | TMP117 25.4x18 | MAX30102 20.6x15.5
//   LTE Cat-M 모듈: 미확정 → 예약 베이 26x28 (M5Stamp/Waveshare급 다 수용)
//   충전모듈: TP4056 (26x17.5) 가정, USB 포트가 +X벽 바깥으로 노출
// ============================================================

// ---------- 출력 선택 ----------
part = "assembly";   // "base" | "lid" | "assembly" (STL 뽑을 땐 base/lid 각각)
show_components = true;   // 부품 고스트 표시 (STL 출력 시 자동 무시)
exploded = 12;            // assembly에서 뚜껑 띄우는 높이 (0 = 닫힘)

// ---------- 주요 파라미터 ----------
wall    = 2.5;    // 측벽 두께
floor_t = 2.0;    // 바닥 두께
lid_t   = 2.2;    // 뚜껑 두께
inner_x = 100;    // 내부 가로 (팔 방향)
inner_y = 70;     // 내부 세로 (손목 둘레 방향)
inner_z = 20;     // 내부 높이 — 점퍼선/커넥터 여유 (널널)
corner_r = 3;

outer_x = inner_x + 2*wall;   // = 105
outer_y = inner_y + 2*wall;   // = 75

strap_w = 26;     // 스트랩(벨크로) 폭 25mm + 여유

// ---------- 베이 위치 (내부좌표, 안쪽 바닥 좌하단 원점) ----------
// ESP32: 앞-왼쪽, USB-C는 -X벽 구멍으로
esp_pos  = [2, 10];   esp_sz  = [24, 19];
// MAX30102: 앞-중앙 (손목 압력이 안정적인 중앙부, 바닥 창)
max_pos  = [40, 4];   max_sz  = [21.5, 16.5];
// TMP117: 앞-오른쪽 (LTE 베이 대각선 반대 = 열 격리 최대)
tmp_pos  = [64, 3];   tmp_sz  = [26, 19.5];
// LTE 예약 베이: 뒤-왼쪽 (넉넉하게 26x28 — 웬만한 Cat-M 보드 다 들어감)
lte_pos  = [4, 32];   lte_sz  = [26, 28];
// 배터리: 뒤-중앙, 세로 방향 포켓
bat_pos  = [36, 32];  bat_sz  = [21, 36];  bat_wall_h = 8;
// GPS: 뒤-오른쪽, 위에 아무것도 없음 (세라믹 패치 하늘 방향)
gps_pos  = [62, 46];  gps_sz  = [23, 22];
// 충전모듈(TP4056): 중간-오른쪽, USB 포트가 +X벽 관통
//   ※ TMP117과 3~4mm 간격 — 충전 중에는 온도 측정값 무시할 것
chg_pos  = [74, 26];  chg_sz  = [26, 18.5];

// 나사 포스트 (M2 셀프태핑)
posts = [[4.5,4.5],[95.5,4.5],[4.5,65.5],[95.5,65.5]];

$fn = 48;

// ============================================================
// 유틸
// ============================================================
module rbox(x, y, z, r=corner_r) {
    linear_extrude(z)
        offset(r=r) offset(delta=-r)
            square([x, y]);
}
// 베이 울타리: 높이 3, 두께 1.2, 각 변 중앙에 배선 통로 6mm
module fence(pos, sz, h=3, t=1.2, gap=6) {
    translate([wall+pos[0], wall+pos[1], floor_t])
    difference() {
        linear_extrude(h) difference() {
            offset(delta=t) square(sz);
            square(sz);
        }
        // 배선 통로 4방향
        translate([sz[0]/2-gap/2, -t-0.1, -0.1]) cube([gap, sz[1]+2*t+0.2, h+0.2]);
        translate([-t-0.1, sz[1]/2-gap/2, -0.1]) cube([sz[0]+2*t+0.2, gap, h+0.2]);
    }
}
module ghost(pos, sz, h, c) {
    if (show_components)
        translate([wall+pos[0], wall+pos[1], floor_t])
            %color(c, 0.55) cube([sz[0], sz[1], h]);
}

// ============================================================
// 본체 (base)
// ============================================================
module base() {
    difference() {
        union() {
            rbox(outer_x, outer_y, floor_t + inner_z);
            // 스트랩 루프 (±Y 장벽 바깥, 하단) — 밴드가 손목을 감는 방향
            for (yy = [-6, outer_y])
                translate([outer_x/2 - strap_w/2 - 4, yy, 0])
                    strap_loop();
            // MAX30102 차광 림 (케이스 바닥 바깥쪽, 검정 필라멘트 권장)
            translate([wall+max_pos[0]+max_sz[0]/2, wall+max_pos[1]+max_sz[1]/2, -1.5])
                linear_extrude(1.5) difference() {
                    offset(r=2) square([9+4, 7+4], center=true);
                    square([9+1, 7+1], center=true);
                }
        }
        // 내부 공동
        translate([wall, wall, floor_t]) cube([inner_x, inner_y, inner_z+1]);
        // MAX30102 광학 창 (9x7 관통)
        translate([wall+max_pos[0]+max_sz[0]/2, wall+max_pos[1]+max_sz[1]/2, -2])
            linear_extrude(floor_t+4) square([9, 7], center=true);
        // TMP117 열전달 박막 (바닥을 0.8mm만 남기고 아래서 제거)
        translate([wall+tmp_pos[0]+tmp_sz[0]/2, wall+tmp_pos[1]+tmp_sz[1]/2, -0.1])
            linear_extrude(floor_t-0.8+0.1) square([14, 10], center=true);
        // ESP32 USB-C 구멍 (-X벽)
        translate([-0.1, wall+esp_pos[1]+esp_sz[1]/2-5, floor_t+1])
            cube([wall+0.2, 10, 6]);
        // 충전모듈 USB 구멍 (+X벽) — 케이스 안 열고 충전
        translate([wall+inner_x-0.1, wall+chg_pos[1]+chg_sz[1]/2-6, floor_t+1])
            cube([wall+0.2, 12, 6]);
        // 나사 파일럿 구멍
        for (p = posts)
            translate([wall+p[0], wall+p[1], floor_t+2])
                cylinder(d=1.8, h=inner_z);
    }
    // 나사 포스트
    for (p = posts)
        translate([wall+p[0], wall+p[1], floor_t])
            difference() {
                cylinder(d=7, h=inner_z);
                translate([0,0,2]) cylinder(d=1.8, h=inner_z);
            }
    // 배터리 포켓 (전용 벽, 위 개방)
    translate([wall+bat_pos[0], wall+bat_pos[1], floor_t])
        difference() {
            linear_extrude(bat_wall_h) difference() {
                offset(delta=1.5) square(bat_sz);
                square(bat_sz);
            }
            // 배선 노치 (앞쪽 벽) — 충전모듈 방향
            translate([bat_sz[0]/2-4, -1.6, bat_wall_h-4]) cube([8, 2, 5]);
        }
    // 모듈 울타리
    fence(esp_pos, esp_sz);
    fence(max_pos, max_sz);
    fence(tmp_pos, tmp_sz);
    fence(lte_pos, lte_sz);
    fence(gps_pos, gps_sz);
    fence(chg_pos, chg_sz);
}
module strap_loop() {
    // 26mm 스트랩용 루프 바
    w = strap_w + 8;
    difference() {
        cube([w, 6, 9]);
        translate([4, -0.1, 2.5]) cube([w-8, 3.6, 4]);
    }
}

// ============================================================
// 뚜껑 (lid)
// ============================================================
module lid() {
    difference() {
        union() {
            rbox(outer_x, outer_y, lid_t);
            // 안쪽 립 (본체 공동에 삽입)
            translate([wall+0.25, wall+0.25, -2])
                rbox(inner_x-0.5, inner_y-0.5, 2, r=2);
        }
        // 나사 관통 + 카운터싱크
        for (p = posts) translate([wall+p[0], wall+p[1], -2.5]) {
            cylinder(d=2.4, h=lid_t+5);
            translate([0,0,2+lid_t-1]) cylinder(d1=2.4, d2=4.6, h=1.1);
        }
        // 트리거 버튼 구멍 (GPIO4, MAX 창과 배터리 포켓 사이 빈 공간 위)
        translate([wall+50, wall+27, -3]) cylinder(d=7.5, h=8);
        // 리셋 접근 구멍 (ESP 위)
        translate([wall+14, wall+25, -3]) cylinder(d=3, h=8);
        // 부저 사운드홀 (LTE 베이 위 뚜껑 안쪽에 부저 접착 — 공간 여유 12mm)
        for (a = [0:60:300])
            translate([wall+17+6*cos(a), wall+46+6*sin(a), -3]) cylinder(d=1.6, h=8);
        translate([wall+17, wall+46, -3]) cylinder(d=1.6, h=8);
        // 라벨 각인
        translate([outer_x/2, wall+8, lid_t-0.6])
            linear_extrude(0.7) text("GCDP HEAT-ALERT PROTO", size=4.2,
                halign="center", font="Arial:style=Bold");
    }
}

// ============================================================
// 부품 고스트 + 출력
// ============================================================
module components() {
    ghost(esp_pos, esp_sz, 5,  "royalblue");  // ESP32-C3
    ghost(max_pos, max_sz, 3,  "red");        // MAX30102
    ghost(tmp_pos, tmp_sz, 3,  "orange");     // TMP117
    ghost(lte_pos, lte_sz, 8,  "purple");     // LTE 예약 (넉넉)
    ghost(bat_pos, bat_sz, 6,  "gray");       // 배터리
    ghost(gps_pos, gps_sz, 6,  "green");      // BE-220 GPS
    ghost(chg_pos, chg_sz, 5,  "hotpink");    // TP4056 충전모듈
}

if (part == "base")  base();
if (part == "lid")   lid();
if (part == "assembly") {
    base();
    components();
    translate([0, 0, floor_t + inner_z + 2 + exploded]) lid();
}

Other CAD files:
hardware/enclosure/260802_parametric_wearable_v01/exports/260802_stamp_catm_pod_lid_v01.step
hardware/enclosure/260802_parametric_wearable_v01/exports/260802_sensor_bar_envelope_v01.step
hardware/enclosure/260802_parametric_wearable_v01/exports/260802_battery_esp_pod_lid_v01.step
hardware/enclosure/260802_parametric_wearable_v01/exports/260802_layout_2pod_comparison_v01.step
hardware/enclosure/260802_parametric_wearable_v01/exports/260802_battery_esp_pod_base_v01.stl
hardware/enclosure/260802_parametric_wearable_v01/exports/260802_battery_esp_pod_lid_v01.stl
hardware/enclosure/260802_parametric_wearable_v01/exports/260802_gps_pod_base_v01.stl
hardware/enclosure/260802_parametric_wearable_v01/exports/260802_gps_pod_lid_v01.stl
hardware/enclosure/260802_parametric_wearable_v01/exports/260802_layout_2pod_comparison_v01.stl
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

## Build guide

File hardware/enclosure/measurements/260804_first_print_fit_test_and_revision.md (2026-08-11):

# 260804 First Print Fit Test And Revision

Date: 2026-08-04

Status: first physical print inspected; geometry corrections required before
wiring-channel authoring

## 1. Gate Result

The first enclosure print is not the wiring-layout baseline yet.

```text
LTE housing:     conditional fail (module fit)
ESP/battery:     conditional pass (USB-C position and buzzer simplification)
GPS housing:     pass for module volume; connector clearance missing
MAX30102 housing: conditional fail (slide fit and supported entrance)
TMP117 housing:  fail (slide fit, support residue, and closure fit)
```

Wiring slots and hinge-crossing channels shall be added only after the changes
below are applied. Otherwise, later fit corrections may erase or misalign the
cable features.

## 2. LTE Housing Revision

Observed facts:

- A nominal 20 x 30 mm module fit is too tight.

Required changes:

1. Make the finished LTE module pocket at least 20.6 x 30.8 mm in plan.
2. If the current print already provides 20.8 mm across the 20 mm module axis,
   retain that width and change only the 30 mm axis.
3. The finished pocket length after printing must be at least 30.6 mm. Do not
   use the observed 28.5 mm result as the next target.
4. Keep the current overall housing height unless a real component collision is
   found; the first print did not identify insufficient vertical room.

## 3. ESP32-C3 And Battery Housing Revision

Observed facts:

- The stacked physical assembly was recorded as 20.8 x 28.5 x 12.9 mm.
- The USB-C opening is vertically misaligned.
- The existing free volume is sufficient for the buzzer; a dedicated buzzer
  compartment is unnecessary.
- The previously reserved buzzer region was approximately 9 x 11 mm.

Required changes:

1. Lower the USB-C cutout by exactly 1.85 mm from its current center position.
2. Remove the dedicated 9 x 11 mm buzzer partition or close-fitting pocket.
3. Retain an unobstructed 9 x 11 mm placement zone and a sound outlet.
4. Do not reduce the 20.8 x 28.5 x 12.9 mm proven assembly envelope during
   this revision.

## 4. GPS Housing Revision

Observed facts:

- The module volume fits.
- The current physical measurement was recorded as 20.7 x 23.7 x 5.3 mm.
- The connector and wire exit do not have a dedicated service volume.

Required changes:

1. Do not enlarge the complete GPS pocket solely for tolerance; its fit passed.
2. Add a connector bay on the connector edge. Initial minimum envelope:
   8 mm along the cable direction, 8 mm across, and 4 mm high.
3. Add a rounded wire exit of approximately 5.0 x 2.5 mm.
4. Add at least R1.0 mm to the wire-contacting slot edges.
5. Keep wiring below the ceramic patch perimeter and never route across its
   outward-facing antenna surface.

The 8 x 8 x 4 mm connector bay is a first-print allowance and must be checked
against the actual terminated connector before the final print.

## 5. MAX30102 Housing Revision

Observed printed slide space:

```text
width:  21.0 mm
height: 1.05 mm
depth:  19.8 mm
```

Observed behavior:

- The board enters but is extremely tight and does not reach the final stop.
- Support removal narrows and roughens the entrance.
- The 2 mm skin-side floor is thicker than required.

Required changes:

1. Increase slide width from 21.0 to 21.5 mm.
2. Increase rail-slot height from 1.05 to 1.55 mm.
3. Do not increase the full 19.8 mm depth by default. First remove entrance and
   rail friction; depth was not proven to be the limiting dimension.
4. Add a 0.6 mm x 45 degree lead-in chamfer at both rail entrances.
5. Add a 0.3 mm elephant-foot relief on bed-facing slot edges.
6. Redesign the slot roof as a self-supporting 45 degree profile so slicer
   support is not generated inside the slide rails.
7. Reduce the skin-side floor from 2.0 to 1.2 mm, while retaining at least
   2.0 mm around the outer frame, hinge, and load-bearing edges.
8. Preserve the optical opening and light-blocking perimeter. The optical
   package must remain the skin-contact high point.

## 6. TMP117 Housing Revision

Observed printed slide/closure dimensions:

```text
width:  18.15 mm
height: 1.60 mm
depth:  29.8 mm
```

Observed behavior:

- The board enters tightly but does not reach the final stop.
- Support removal affects the slide path.
- The closure/lid cannot enter at all.
- The 2 mm skin-side floor is thicker than required.

Required changes:

1. Increase slide width from 18.15 to 18.50 mm.
2. Increase rail-slot height from 1.60 to 1.95 mm.
3. Retain the current 29.8 mm depth unless inspection finds a physical rear
   collision; depth is already greater than the nominal board length.
4. Add a 0.6 mm x 45 degree lead-in chamfer and 0.3 mm elephant-foot relief.
5. Use a self-supporting 45 degree slot roof and block slicer support inside the
   rail path.
6. Reduce the skin-side floor from 2.0 to 1.2 mm, retaining a 2.0 mm perimeter
   frame and the current reinforced hinge geometry.
7. Give the closure tongue 0.6 mm total planar clearance relative to its mating
   opening, equivalent to 0.3 mm per side.
8. Give the closure insertion thickness at least 0.35 mm clearance and add a
   0.5 mm x 45 degree lead-in chamfer.
9. Keep the central thermal-contact region free of wire bundles and thick ribs.

## 7. Printability Rules For Both Sensor Housings

- No generated support is permitted inside a functional slide rail.
- Print the largest closed outer face on the bed when practical.
- Use 45 degree roofs or short bridges over narrow slots.
- Use 0.3 mm elephant-foot relief on all insertion openings touching the bed.
- Keep the sensor-contact membrane at 1.2 mm and the structural perimeter at
  2.0 mm or more.
- Fit must be verified without sanding the PCB before final enclosure printing.
- Print only fit coupons or the two sensor housings after this revision. A full
  five-section reprint is unnecessary at this gate.

## 8. Revision Order

```text
1. LTE pocket length and USB-C position
2. ESP/battery USB-C position and buzzer partition removal
3. GPS connector bay and wire exit
4. MAX30102 slide clearance and support-free entrance
5. TMP117 slide and closure clearance
6. Print fit coupons / sensor housings
7. Confirm full insertion and closure by hand
8. Freeze module pockets
9. Author wiring channels and hinge free-loop clearances
```

## 9. Milestone Status

```text
Mechanical architecture selected: complete
Hinge concept and first hinge print: complete
First enclosure fit print: complete
Fit-correction geometry: in progress
Fit-correction print verification: pending
Wiring-channel CAD: blocked by fit-correction gate
Final enclosure print: pending
```

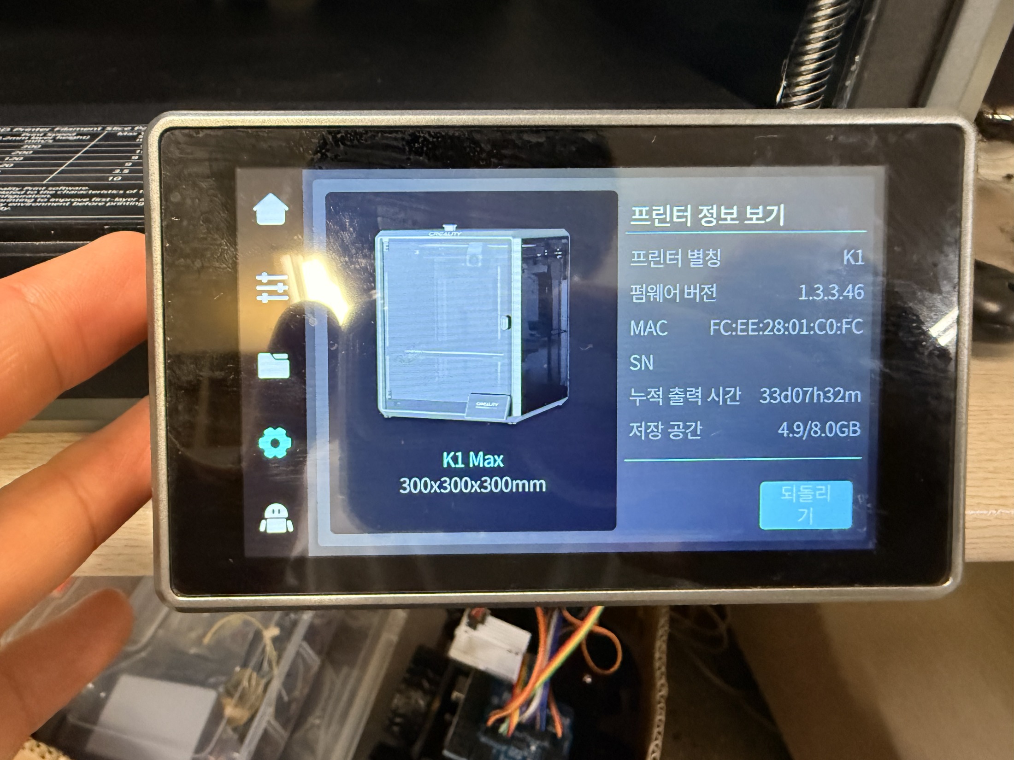
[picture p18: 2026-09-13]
evidence/3d-printing/02_프린터_설정참고/260803_printer_device_information.jpg

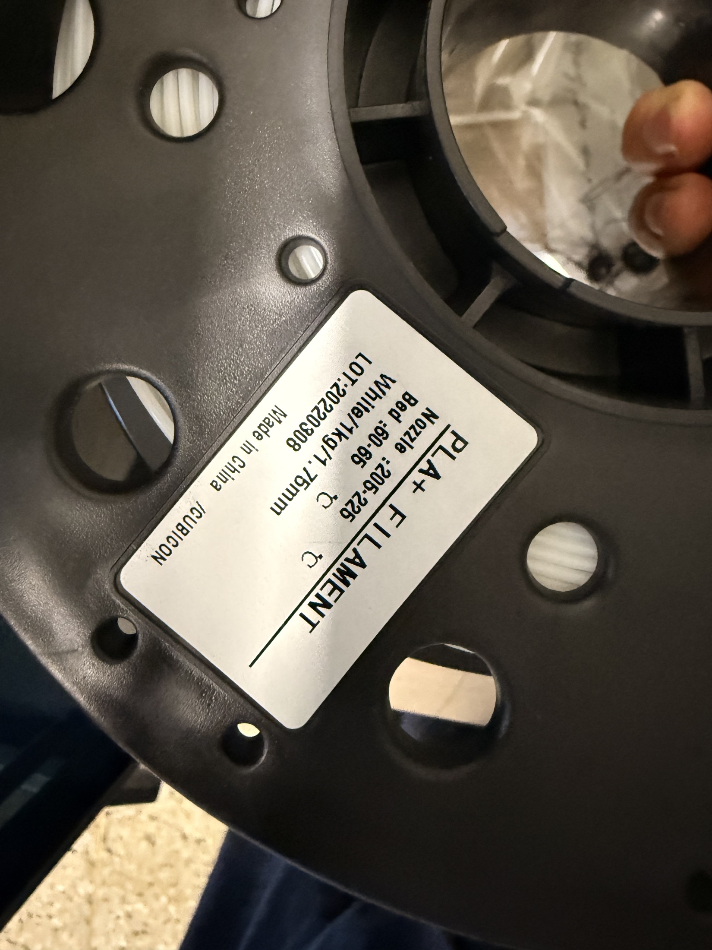
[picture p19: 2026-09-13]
evidence/3d-printing/02_프린터_설정참고/260803_filament_spool_label_01.jpg

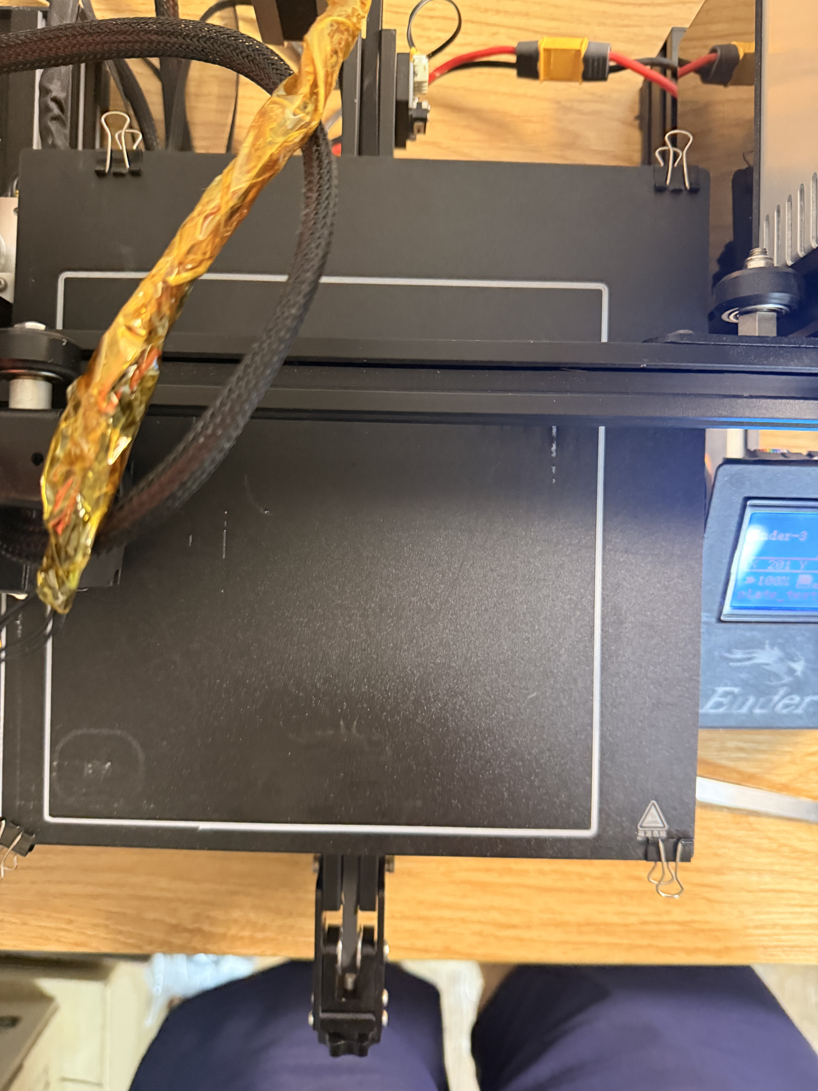
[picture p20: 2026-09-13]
evidence/3d-printing/01_출력_증빙/260810_print_1472.png

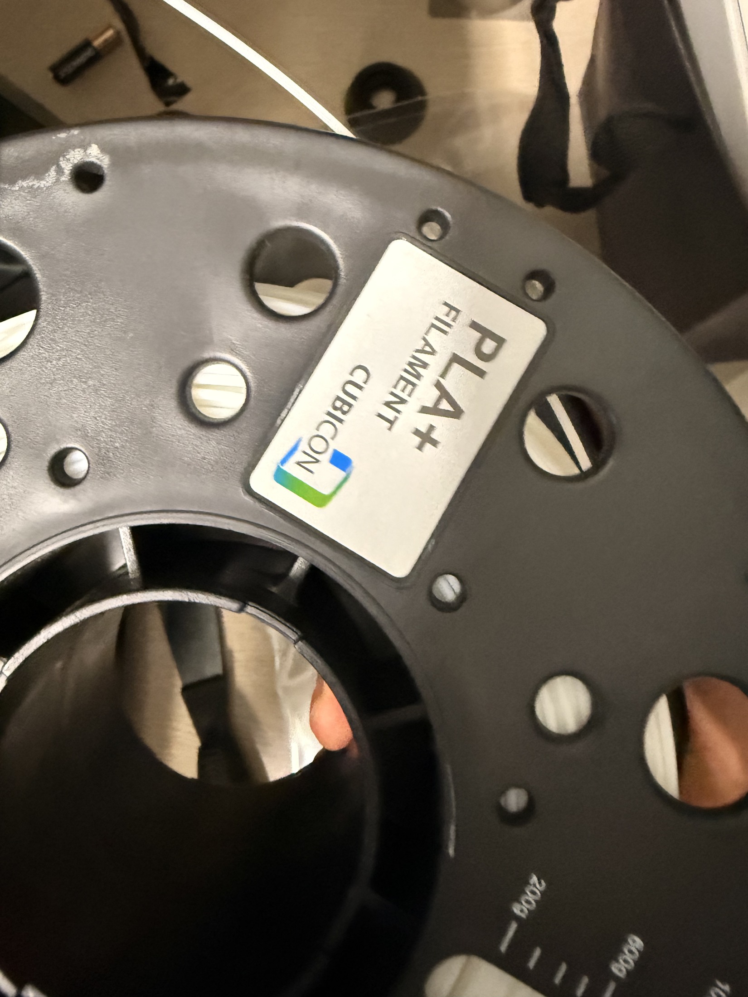
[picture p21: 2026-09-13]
evidence/3d-printing/02_프린터_설정참고/260803_filament_spool_label_02.jpg

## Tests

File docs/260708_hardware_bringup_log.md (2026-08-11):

# 2026-07-08 Hardware Bring-Up Log

Project: Heat Risk Alert Wristband  
Workspace: GCDP 하계(Korea)  
Purpose: Initial firmware environment setup and hardware bring-up for MCU, sensors, buzzer, and SIM7080G LTE module.

## 1. Development Environment

### Temporary Firmware Workspace

The firmware development workspace was moved from the cloud-synced `N:` drive to a local temporary directory to avoid PlatformIO build/cache issues.

Active firmware path:

```text
C:\Users\sukhe\Desktop\GCDP_codex_temp\firmware
```

### Tooling

Installed and verified:

- PlatformIO Core
- VS Code PlatformIO IDE extension
- VS Code C/C++ extension
- Espressif32 PlatformIO platform
- ESP32 and ESP32-C3 toolchains

### PlatformIO Environments

The following PlatformIO environments were created and build-tested:

- `esp32dev`
- `xiao_esp32c3`
- `esp32c3_supermini`

All three environments compiled successfully.

## 2. MCU Bring-Up

### ESP32-C3 Board

The USB-C ESP32-C3 board was detected by Windows and PlatformIO as:

```text
COM6
USB VID:PID=303A:1001
ESP32-C3
USB-Serial/JTAG
MAC: 44:b1:76:19:d5:f0
```

`esptool.py chip_id` confirmed:

```text
Chip is ESP32-C3 AZ (QFN32) revision v1.1
Embedded Flash 4MB
USB mode: USB-Serial/JTAG
```

Firmware upload to the ESP32-C3 board succeeded.

### ESP32 DevKitC WROOM-32U

The micro USB ESP32 DevKitC was detected as a CP2102 USB-UART device, but Windows reported a driver installation failure.

Observed device:

```text
CP2102 USB to UART Bridge Controller
Status: Error
Problem: CM_PROB_FAILED_INSTALL
```

The board was not used further during this session.

## 3. Firmware Structure

Initial PlatformIO firmware files were created under:

```text
C:\Users\sukhe\Desktop\GCDP_codex_temp\firmware
```

Main files:

- `platformio.ini`
- `src/main.cpp`
- `include/pins.h`
- `README.md`

Initial firmware functions implemented during the session:

- I2C scan
- TMP117 temperature read
- MAX30102 part ID read
- MAX30102 raw RED/IR sampling
- Buzzer GPIO control
- SIM7080G UART AT diagnostic scanning

## 4. I2C Bus Configuration

ESP32-C3 I2C pin configuration:

```text
SDA = GPIO6
SCL = GPIO7
```

Both sensors were connected on the same I2C bus.

Expected I2C addresses:

```text
TMP117   = 0x48
MAX30102 = 0x57
```

## 5. MAX30102 Heart-Rate Sensor Test

### Wiring

MAX30102 pins used:

```text
VIN -> ESP32-C3 3V3
GND -> ESP32-C3 GND
SDA -> ESP32-C3 GPIO6
SCL -> ESP32-C3 GPIO7
```

Unused MAX30102 pins:

```text
D
IRO
INT
extra GND
```

### I2C and Part ID Test

The sensor was detected on the I2C bus:

```text
[i2c] found 0x57
```

MAX30102 part ID read succeeded:

```text
[max30102] part id 0x15
```

### Raw Data Test

MAX30102 RED/IR raw data was successfully read.

Example observed values with finger on sensor:

```text
red = 104552
ir  = 130099
```

Later continuous sampling produced approximately:

```text
Sample rate: 49.98 Hz
RED range: 107248 to 107786
IR range: 133719 to 134472
```

The captured waveform file was saved at:

```text
C:\Users\sukhe\Desktop\GCDP_codex_temp\firmware\captures\max30102_waveform_20260708_173314.csv
```

### BPM Estimate

A crude peak detector estimated:

```text
Mean BPM:   115.2
Median BPM: 115.4
```

This was treated as a preliminary waveform validation, not a final heart-rate algorithm.

## 6. TMP117 Temperature Sensor Test

### Wiring

TMP117 pins used:

```text
VIN -> ESP32-C3 3V3
GND -> ESP32-C3 GND
SDA -> ESP32-C3 GPIO6
SCL -> ESP32-C3 GPIO7
```

Unused TMP117 pins:

```text
INT
ADDR
```

### Simultaneous I2C Test

With both TMP117 and MAX30102 connected, the I2C scan detected both sensors:

```text
[i2c] found 0x48
[i2c] found 0x57
```

TMP117 temperature readings were successfully observed:

```text
32.84 C
33.01 C
33.12 C
33.21 C
```

MAX30102 raw RED/IR data continued to work at the same time.

Conclusion: TMP117 and MAX30102 worked simultaneously on the same I2C bus.

## 7. Wear Detection and Buzzer Test

### Buzzer Wiring

The active buzzer was connected to:

```text
ESP32-C3 GPIO10
```

### Test Logic

Firmware was updated so that:

- Finger/contact detected: buzzer ON
- Finger/contact removed: buzzer OFF

Initial IR thresholds:

```text
wear on  threshold: 80000
wear off threshold: 60000
```

### Result

Wear detection worked with low perceived delay. The buzzer turned on/off when contact state changed.

Observed serial events included:

```text
# wear detected ir=127793
# wear removed ir=1013
# wear detected ir=128071
# wear removed ir=1023
```

The user confirmed the delay was acceptable for the current prototype stage.

## 8. SIM7080G Small Module Test

### Small Module Pins

The small SIM7080G CAT-M module had these labeled pins:

```text
5V
3V3
GND
Rf
Tx
Rx
```

### Initial Connection

Connection attempted:

```text
SIM7080G GND -> ESP32-C3 GND
SIM7080G 5V  -> 5V power
SIM7080G Tx/Rx -> ESP32-C3 GPIO20/GPIO21 combinations
```

`Rf` was not connected to the ESP32-C3.

### Result

The module LED turned on, but no AT response was received.

Firmware scanned:

- normal TX/RX direction
- swapped TX/RX direction
- baud rates: `115200`, `9600`, `57600`, `38400`, `19200`

Result:

```text
AT -> no response
```

Conclusion: The small module was not successfully brought up during this session.

Possible causes:

- module body not powered on
- hidden PWRKEY/boot requirement
- UART pins not active
- board-specific power or level-shifter condition

## 9. SIM7080G Developer Kit Test

### Developer Kit Pin Labels

The developer kit exposed these pins:

```text
DTR
GND
VDD
PWRK
UTX
URX
GND
```

It also had:

- micro USB connector
- 4-pin connector
- three antenna connectors

PCB markings observed:

```text
CAT-1-A76-80X
NB-SIM-7080
SIM-800/868
```

### USB Test

The developer kit was connected to the PC via micro USB.

Result:

- LED turned on.
- No new COM port appeared in Windows.
- Only the existing ESP32-C3 COM6 port was detected.

Possible cause:

- micro USB cable may have been power-only
- developer kit USB may not expose USB-UART
- driver not applicable or device not enumerating

### UART Pin Test Through ESP32-C3

The developer kit was then connected to the ESP32-C3 UART pins.

Working connection after diagnosis:

```text
DevKit UTX -> ESP32-C3 GPIO21
DevKit URX -> ESP32-C3 GPIO20
DevKit GND -> ESP32-C3 GND
```

The developer kit was powered separately via micro USB.

### Power Key

The developer kit required a power-key action.

Action performed:

```text
PWRK -> GND for approximately 1 to 2 seconds, then released
```

After this, a green LED began blinking.

### AT Command Success

UART diagnostic succeeded after PWRK activation.

Successful UART configuration:

```text
ESP32-C3 RX = GPIO21
ESP32-C3 TX = GPIO20
baud = 115200
```

Observed AT response:

```text
AT
OK
```

Observed ATI response:

```text
ATI
R1951.07
OK
```

Conclusion: SIM7080G developer kit UART bring-up succeeded.

## 10. SIM Status

No SIM card was available during this session.

The user noted that their phone uses eSIM, so no physical SIM was available for SMS or network registration testing.

SIM-dependent tests were not performed:

- LTE network registration
- signal quality with valid SIM
- SMS transmission
- emergency SMS workflow

SIM-independent tests that succeeded:

- SIM7080G developer kit power-on via PWRK
- UART communication
- AT command response
- firmware version query via ATI

## 11. Current Hardware Status

### Confirmed Working

- ESP32-C3 firmware upload and serial monitoring
- MAX30102 I2C communication
- MAX30102 raw RED/IR sampling
- TMP117 I2C communication
- TMP117 temperature reading
- simultaneous TMP117 + MAX30102 I2C operation
- buzzer output on GPIO10
- IR-threshold-based wear detection
- SIM7080G developer kit UART AT command communication

### Not Yet Completed

- CP2102 driver setup for ESP32 DevKitC WROOM-32U
- small SIM7080G module AT communication
- SIM card test
- LTE network registration
- SMS sending
- GNSS/GPS test
- battery/Li-Po power test
- integrated emergency state machine

## 12. Next Recommended Tests

1. Run SIM7080G developer kit command sequence:

```text
AT
ATI
AT+CGMM
AT+CGMR
AT+CPIN?
```

2. Obtain a physical SIM card that supports LTE Cat-M or compatible LTE service.

3. Test:

```text
AT+CPIN?
AT+CSQ
AT+CEREG?
```

4. Test SMS send workflow.

5. Test GNSS separately.

6. Restore or refactor firmware from diagnostic mode into modular bring-up modes:

- sensor mode
- wear detection mode
- LTE diagnostic mode
- integrated emergency workflow mode

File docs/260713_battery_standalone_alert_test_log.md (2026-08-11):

# 2026-07-13 Battery Standalone Alert Test Log

Project: Heat Risk Alert Wristband  
Purpose: Verify the prototype can run the alert flow from Li-Po battery power, including sensor measurement, SIM7080G boot/control, GNSS acquisition, and SMS transmission.

## 1. Scope

This log records the work performed after the earlier LTE/SMS integration tests.

Main goals:

- Confirm ESP32-C3 SuperMini can operate from external power while USB debug remains usable.
- Confirm SIM7080G can boot from Li-Po/battery-side power.
- Confirm SIM7080G LTE + GNSS + SMS works while powered from the battery path.
- Confirm the full prototype can run from battery power without relying on the laptop for operation.
- Add a standalone trigger flow with buzzer feedback for field demonstration.
- Re-check MAX30102 heart-rate and TMP117 temperature data after the standalone firmware changes.

## 2. Hardware Used

### MCU

ESP32-C3 SuperMini.

Observed / used points:

- USB-C used for firmware upload and serial debug.
- `5V` pin was used as the external input during full battery testing.
- `3V3` pin output was measured at approximately 3.3 V when the Li-Po battery was connected to the `5V` pin.
- The ESP32-C3 SuperMini was not planned to be integrated as a bare MCU on the first PCB. For the first prototype, it remains a mounted development board/module.

### Cellular / GNSS

SIM7080G developer board/module.

Used points:

- `VDD` and `GND` for module power during battery tests.
- UART connected to ESP32-C3 SuperMini.
- `PWRK` connected to ESP32-C3 GPIO5.
- LTE/GNSS antennas connected before GNSS/SMS tests.

Important observed behavior:

- The module did not always boot immediately after power application.
- User confirmed that applying the PWRK signal for about 1 second is enough to start the module.
- Practical boot time after PWRK was observed at about 7 seconds.

### Sensors

TMP117 precision temperature sensor:

- I2C address used: `0x48`.
- Connected to the shared I2C bus.
- Verified temperature read after firmware changes.

MAX30102 heart-rate / PPG sensor:

- I2C address used: `0x57`.
- Connected to the shared I2C bus.
- Finger placement test performed during `MEASURE`.
- Verified heart-rate estimation after firmware changes.

### Buzzer

3 V active buzzer.

- Connected to ESP32-C3 GPIO10.
- Used for standalone demo feedback.
- The buzzer initially stayed active in some error states; firmware was changed so the normal state-machine buzzer is disabled for the standalone demo build, and only explicit event beeps are used.

### Battery

Li-Po TW-602035 battery.

Known product data:

- Nominal voltage: 3.7 V
- Capacity: 380 mAh
- Energy marking: 1.406 Wh
- Approximate size: 20 mm x 35 mm x 6 mm
- Connector: 1.25 mm 2-pin type

Measured before battery tests:

```text
Battery voltage: about 3.989 V
After SIM7080G boot: about 3.97 V
```

## 3. Final Working Pin Map

Firmware environment: `esp32c3_supermini`

```text
I2C SDA: ESP32-C3 GPIO8
I2C SCL: ESP32-C3 GPIO9

SIM7080G UART:
  ESP32-C3 RX = GPIO20
  ESP32-C3 TX = GPIO21

Buzzer:
  ESP32-C3 GPIO10

SIM7080G PWRK:
  ESP32-C3 GPIO5

Standalone trigger:
  ESP32-C3 GPIO4
  Active-low trigger to GND
```

Important UART note:

- The firmware uses ESP RX = GPIO20 and ESP TX = GPIO21.
- The physical UART wiring only worked after swapping the two signal wires compared with the earlier non-working wiring.
- Before the swap, measured idle voltages were:

```text
SIM7080G TX: about 3.25 V
SIM7080G RX: about 3.07 V
ESP GPIO20: about 3.1 V
ESP GPIO21: about 3.265 V
```

Conclusion: preserve the currently working physical UART wiring. Do not rely only on the printed TX/RX labels without validating AT response.

## 4. Test 3: ESP32-C3 External 3.3 V + USB Debug

Purpose:

- Check whether the ESP32-C3 SuperMini can be externally powered while USB remains connected for debug/upload.

Setup:

```text
PSU connected to ESP32-C3 3V3 and GND
ESP32-C3 USB connected to laptop
Other wiring kept in place
```

Observed:

```text
Current draw: about 0.02 A to 0.03 A
USB debug/upload remained available
No immediate conflict observed
```

Result:

```text
PASS
```

Interpretation:

- External 3.3 V with USB debug did not immediately cause an operational issue.
- This was useful for bench testing, but not the final battery architecture.
- For full battery operation, the test moved to Li-Po input through the ESP32-C3 `5V` pin.

## 5. SIM7080G Battery Power Test

Purpose:

- Confirm SIM7080G can boot and perform LTE/GNSS/SMS when powered from the Li-Po/battery path.

Setup:

```text
ESP32-C3: USB connected for debug
Sensors: powered from ESP32-C3 3V3
SIM7080G: Li-Po connected to VDD and GND
All grounds common
```

Observed:

```text
Battery before/around test: about 3.989 V
After SIM7080G green LED came on: about 3.97 V
Green LED: on/blinking after PWRK action
```

The user confirmed:

```text
SMS received
Voltage drop was negligible for this test
```

Result:

```text
PASS
```

Interpretation:

- SIM7080G was able to boot from the battery-side power path.
- LTE/GNSS/SMS operation did not create an obvious voltage-collapse problem in this test.
- The first PCB still needs proper power design, because the dev board's `VDD` behavior is not identical to a final bare-module `VBAT` design.

## 6. Full Battery System Test

Purpose:

- Confirm the full prototype can run without laptop power.

Setup:

```text
Li-Po positive -> ESP32-C3 5V pin
Li-Po positive -> SIM7080G VDD
Li-Po negative -> common GND

ESP32-C3 3V3 -> TMP117 VIN
ESP32-C3 3V3 -> MAX30102 VIN
ESP32-C3 3V3 -> buzzer supply/control path
All grounds common
```

Additional observation:

```text
ESP32-C3 3V3 pin measured about 3.3 V while Li-Po was connected to ESP32-C3 5V pin.
```

User-confirmed result:

```text
SMS received
No meaningful voltage problem observed
```

Result:

```text
PASS for prototype demonstration
```

Engineering caution:

- Li-Po must not be connected directly to ESP32-C3 `3V3`.
- The tested path was Li-Po to the ESP32-C3 `5V` pin, then sensors from ESP32-C3 `3V3`.
- For the PCB, the power path should be explicitly designed instead of assuming the development board's regulator behavior.

## 7. Standalone Demo Flow

The standalone test mode was added so the device can be operated without serial commands.

Trigger:

```text
GPIO4 held LOW to GND for about 1.5 seconds
```

Standalone operation:

```text
1. Start beep
2. Wait about 5 seconds for finger/sensor placement
3. Measurement begins
4. Measurement complete -> two beeps
5. SIM7080G AT check
6. If needed, PWRK HIGH for 1000 ms
7. Wait about 7 seconds for SIM7080G boot
8. LTE registration
9. GNSS acquisition
10. SMS send
11. SMS success -> three beeps
```

Buzzer result codes:

```text
1 beep  : standalone test start
2 beeps : sensor measurement complete
3 beeps : SMS success
4 beeps : modem AT response failure
5 beeps : LTE registration failure
6 beeps : SMS send failure
```

Issue observed:

- The buzzer kept sounding in an earlier build.
- Measurement also felt too long because completion feedback was not heard.

Firmware changes made:

- Heart-rate measurement duration set to 5 seconds.
- Normal state-machine buzzer disabled for the demo build with `ENABLE_STATE_BUZZER=0`.
- Buzzer now mainly provides explicit event/result codes.
- SIM7080G PWRK timing changed to match observed behavior:

```text
PWRK HIGH: 1000 ms
Modem boot wait: 7000 ms
```

## 8. SIM7080G Boot / UART Issue

Problem:

- Standalone test sometimes failed with 4 beeps, meaning modem AT response failure.
- User confirmed SIM7080G could physically boot, but firmware could not always get AT response.

Actions:

- Rechecked UART pin definitions.
- Rechecked physical TX/RX wiring.
- Used LTE probe behavior to test the UART response.
- Changed standalone boot logic so it does not wait unnecessarily before applying PWRK.

Final behavior:

- SIM7080G boot takes about 7 seconds after PWRK.
- After the UART wiring correction and PWRK timing change, standalone eventually produced 3 beeps, meaning SMS success.

Result:

```text
PASS after UART/PWRK corrections
```

## 9. Sensor Measurement Recheck

Problem:

- After the standalone SMS path worked, the user noticed heart-rate and temperature were not visible in the received message.
- Sensor function was rechecked directly with the user placing a finger on the MAX30102.

Command/test:

```text
MEASURE
```

Observed successful measurement:

```text
MAX30102:
  samples = 94
  peaks = 6
  bpm = 76.6
  mean = 127970.5
  amplitude = 487.0

TMP117:
  temp_ok = 1
  temperature = 22.66 C

Wear detection:
  worn = 1

State:
  ERROR -> NORMAL after valid sensor data
```

Result:

```text
PASS
```

Interpretation:

- MAX30102 and TMP117 were both readable after the firmware changes.
- The lack of heart-rate/temperature in the SMS is likely a message-format or standalone data-handling issue, not a basic sensor hardware failure.
- Next firmware task is to ensure `STANDALONE` inserts the latest measured `bpm` and `tempC` into the SMS body every time.

## 10. Current Verified Status

Verified by direct test:

```text
ESP32-C3 SuperMini external power + USB debug: PASS
SIM7080G boot from battery-side power: PASS
SIM7080G LTE registration: PASS
SIM7080G GNSS coordinate acquisition: PASS
SIM7080G SMS transmission: PASS
Full prototype battery-powered SMS path: PASS
Standalone trigger and buzzer feedback: PASS after fixes
MAX30102 heart-rate measurement: PASS
TMP117 temperature measurement: PASS
```

Known working GNSS area from tests:

```text
Latitude: about 36.05
Longitude: about 127.33
```

## 11. Remaining Work Before Case / PCB Freeze

Firmware:

- Ensure standalone SMS body always includes:

```text
HR: <bpm>, TEMP: <temperature>, LOC: <lat>, <lon>
```

- Avoid repeated automatic SMS transmission. SMS must remain trigger-based.
- Keep the SMS destination configurable for demonstration.

Power:

- Repeat full battery test while watching voltage with oscilloscope if time permits.
- Confirm behavior at lower battery voltage, not only around 3.97 to 3.99 V.
- Add proper power architecture in PCB design instead of relying on development board regulator behavior.

Mechanical:

- Design a wearable enclosure that holds the sensor surfaces against the skin.
- Keep SIM7080G/LTE heat away from TMP117.
- Provide antenna clearance and cable strain relief.
- Provide USB/debug access during prototype phase.
- Provide a simple trigger button or exposed test pads for GPIO4-to-GND standalone start.

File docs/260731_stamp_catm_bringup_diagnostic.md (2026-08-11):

# 2026-07-31 Stamp CatM Bring-Up Diagnostic

## 1. Purpose

Verify whether the M5Stack Stamp CatM S003 can boot its SIM7080G modem and
respond to UART AT commands. Separate power, ESP32 UART, USB-UART, wiring, and
modem hardware causes using only available project parts.

## 2. Hardware

- M5Stack Stamp CatM S003
- Main ESP32-C3 SuperMini connected to the laptop
- Spare ESP32-C3 SuperMini used only as a USB 5 V breakout
- SEENGREAT FT232 USB-UART bridge, VCCIO switch set to 3.3 V
- INA219 high-side current sensor module
- USB charger or power-bank source for the spare SuperMini

## 3. Final Diagnostic Wiring

Power path:

```text
USB source
  -> spare SuperMini USB
  -> spare SuperMini 5V
  -> INA219 VIN+
  -> INA219 VIN-
  -> Stamp CatM 5V
```

UART path:

```text
Stamp TX -> FT232 RXD
Stamp RX <- FT232 TXD
Stamp GND <-> FT232 GND
```

INA219 logic:

```text
INA219 VCC -> main ESP32-C3 3.3V
INA219 GND -> common GND
INA219 SDA -> main ESP32-C3 GPIO8
INA219 SCL -> main ESP32-C3 GPIO9
```

All grounds were common. Stamp `3V3`, `Rf`, FT232 `VCCIO`, `RTS`, and `CTS`
were not connected.

## 4. Tests and Observations

### 4.1 ESP32 UART test

The Stamp was first connected to the main ESP32-C3 UART:

```text
Stamp TX -> ESP32-C3 GPIO20 (RX)
Stamp RX <- ESP32-C3 GPIO21 (TX)
```

Observed line states:

```text
GPIO20 / Stamp TX: LOW for all samples, no transitions
GPIO20 internal pull-up test: remained LOW
GPIO21 / Stamp RX: HIGH when driven by ESP32 UART
```

Removing the Stamp TX wire allowed GPIO20 to follow its internal pull-up and
pull-down. Therefore, the ESP32 GPIO was healthy and the Stamp side was holding
its TX line LOW.

AT probes at 115200, 9600, 19200, 38400, 57600, 74880, and 230400 baud
returned no response.

### 4.2 Dedicated USB 5 V source

The Stamp was powered separately through the 5 V pin using a spare SuperMini
connected to a USB source. The main ESP32 remained connected to the laptop,
with common ground.

Result:

```text
Stamp TX remained LOW
No UART AT response
No improvement over the original USB power arrangement
```

### 4.3 FT232 direct UART test

The main ESP32 UART was removed from the modem path. FT232 was connected
directly to the Stamp with 3.3 V UART logic.

Windows detected the bridge as:

```text
FT232: COM5
Main ESP32-C3: COM6
```

Direct AT probes were performed at:

```text
9600
19200
38400
57600
74880
115200
230400
460800
921600
```

Each baud was tested three times. No received byte was observed at any baud.

### 4.4 FT232 loopback verification

FT232 TXD and RXD were connected directly together. A 33-byte test payload was
transmitted.

```text
Transmitted bytes: 33
Received bytes: 33
Exact content match: true
```

This confirmed the laptop, COM5 driver, FT232 transmitter, and FT232 receiver
were functioning.

### 4.5 INA219 power measurement

INA219 was detected on the main ESP32-C3 I2C bus:

```text
I2C address: 0x40
```

The Stamp input was measured for 15 seconds while FT232 transmitted `AT`
twelve times.

Measured result:

```text
Samples: 149
Stamp load voltage minimum: 5.044 V
Stamp load voltage average: 5.083 V
Stamp load voltage maximum: 5.088 V

Input current minimum: 11.0 mA
Input current average: 12.3 mA
Input current maximum: 32.5 mA

FT232 AT commands sent: 12
FT232 received bytes: 0
INA219 overflow: none
```

The current calculation assumes the INA219 module uses an `R100` 0.1-ohm
shunt. The voltage result does not depend on this current-shunt assumption.

### 4.6 Component-level voltage diagnosis

The Stamp was re-tested with a multimeter and the ESP32-C3 UART.

External Stamp pins:

```text
5V: 5.27 V
3V3: 3.415 V
TX: 3.398 V
RX: 3.25 V
```

SIM7080 package-side points:

```text
VDD_EXT, pin 40: 1.803 V
STATUS, pin 42: 1.803 V
UART1_TXD, pin 1: 1.803 V
UART1_RXD, pin 2: 1.72 V
```

Grounding the external Stamp RX input pulled SIM7080 UART1_RXD to about
1.5 mV. This verified the Stamp RX level-shifter path.

### 4.7 UART dynamic tests

The ESP32-C3 firmware was extended with controlled UART line tests.

`UARTTXTEST` drove ESP32-C3 GPIO21 LOW and HIGH in two-second intervals.
The SIM7080 UART1_RXD package pin followed between approximately 0 V and
1.7-1.8 V.

`UARTRXTEST` counted transitions on ESP32-C3 GPIO20 while transmitting AT
commands at several baud rates. Results included:

```text
115200 baud:
  596 and 711 detected edges
  72 and 90 decoded bytes

Other tested baud rates:
  about 130 detected edges
  zero valid decoded bytes
```

`LTEPROBE` then received:

```text
AT   -> OK
ATE0 -> OK
```

This proved that the modem had booted and that both UART directions worked at
115200 baud. The earlier no-response result was not a modem hardware failure.

### 4.8 SIM orientation and detection

With the SIM in the initial orientation, network commands reported SIM
detection errors. The SIM was rotated 180 degrees and the modem was fully
restarted.

After restart:

```text
AT+CPIN? -> READY
AT+CCID  -> ICCID read successfully
AT+CIMI  -> IMSI read successfully
```

The current, rotated SIM orientation is the verified orientation. SIM identity
values are intentionally omitted from this shared record.

### 4.9 Antenna and network scan

The LTE antenna was connected to the Stamp IPEX connector before RF tests.

Confirmed modem configuration:

```text
Model response: SIMCOM_SIM7080
Firmware: 1951B17SIM7080
Initial network mode readback: automatic, CNMP=2
Preferred LPWA mode: Cat-M only
Cat-M bands: B1/B2/B3/B4/B5/B8/B12/B13/B14/B18/B19/B20/
             B25/B26/B27/B28/B66/B85
```

Observed signal strength ranged from `CSQ 22` to `CSQ 31`. The antenna and RF
receive path therefore worked.

An uninterrupted full operator scan returned:

```text
45005, SKT: available
45012, SKT IoT PLMN: available
45008, KT: forbidden
45006, LG U+: forbidden
45030: forbidden
```

### 4.10 Network registration attempts

Automatic registration remained unsuccessful:

```text
AT+COPS?  -> mode 0, automatic
AT+CEREG? -> 0,2 while searching
AT+CGATT? -> 0
AT+CPSI?  -> NO SERVICE
```

Manual registration attempts were then made:

```text
AT+COPS=1,2,"45005",7 -> CME ERROR: no network service
AT+COPS=1,2,"45012",7 -> CME ERROR: no network service
AT+CEREG?              -> 0,3, registration denied
```

The modem was returned to automatic operator selection:

```text
AT+COPS?  -> 0
AT+CEREG? -> 0,3
AT+CSQ    -> 23,99
```

The modem could see both SKT PLMNs with strong RF signal, but the initial
registration attempt was rejected. This was the pre-remediation result, not
the final result.

## 5. Reference Values

The official M5Stack Stamp CatM documentation specifies:

```text
Supply and standby: DC 5 V at 46 mA
Network access current: DC 5 V at 71 mA
UART: 115200 baud, 8N1
```

The official schematic shows:

```text
5 V input -> onboard GM9308/HM8089 converter -> 3.3 V rail
3.3 V rail -> SIM7080G VBAT
Red power LED -> 3.3 V rail
SIM7080G PWRKEY pin 39 linked to STATUS pin 42 through R4, 0 ohm
```

## 6. Final Result

```text
USB 5 V source: PASS
Stamp input voltage: PASS
Stamp onboard 3.3 V rail: PASS
INA219 measurement path: PASS
ESP32 UART GPIO: PASS
FT232 direct UART: PASS
FT232 loopback: PASS
Stamp UART level shifting: PASS
SIM7080 modem boot: PASS
UART AT communication at 115200 8N1: PASS
SIM detection after orientation correction: PASS
LTE antenna and RF reception: PASS
Korean operator scan: PASS
Initial SKT network registration: FAIL - registration denied
SKT network registration after stored-setting cleanup: PASS
```

The initial modem-fault conclusion was disproved by package-pin voltage checks,
controlled UART transition tests, and successful AT responses. The Stamp
hardware is operational.

`CEREG 0,3` was real, but the later successful registration proves that it did
not establish a carrier-account fault. The Stamp had stale or unsuitable
stored modem settings. A controlled cleanup and Cat-M configuration resolved
the registration without changing the SIM or asking the carrier to modify the
subscription.

## 7. Decision and Next Action

The Stamp CatM is electrically and operationally usable and remains the compact
LTE module candidate. Replacement is not justified by the test results.

Priority actions:

1. Preserve the verified Cat-M initialization settings in firmware.
2. Perform one controlled SMS transmission test with the Stamp.
3. Repeat battery-only operation with Stamp, ESP32-C3, sensors, and GPS.
4. Continue BE-220 GPS integration and enclosure work.
5. Contact the carrier only if registration fails again after the verified
   initialization sequence.

## 8. Firmware Changes Made for Diagnosis

The integrated firmware gained these manual diagnostic commands:

```text
I2CSCAN
POWERMON [seconds]
UARTTXTEST
UARTRXTEST
ATCMD <command>
ATLONG <seconds> <command>
```

`POWERMON` reads INA219 bus and shunt voltage, prints approximately 10 samples
per second, and reports minimum, average, and maximum load voltage and current.
`ATLONG` allows uninterrupted long-running modem commands such as full operator
scans. No SMS was transmitted during this diagnostic.

## 9. Milestone Status

```text
Stamp power bring-up: COMPLETE
Stamp UART bring-up: COMPLETE
SIM orientation/detection: COMPLETE
LTE antenna/RF validation: COMPLETE
Korean operator visibility: COMPLETE
SKT Cat-M registration on PLMN 45005: COMPLETE
Packet attachment: COMPLETE
Stamp SMS test: PENDING CONTROLLED SINGLE-SMS TEST
```

## 10. Comparison With the Previously Successful Board

The previously tested SIM7080 developer board was rechecked in the earlier
development records. It was not operating as a different Cat-1 radio:

```text
Previous developer board
ATI: R1951.07
AT+CNMP?: 38, LTE only
AT+CMNB?: 1, Cat-M only
Registered PLMN: 45005, SKT
AT+CEREG?: registered
AT+CGATT?: 1
SMS transmission: PASS

Current Stamp CatM
ATI: R1951.07
Initial AT+CNMP?: 2, automatic
AT+CMNB?: 1, Cat-M only
Visible PLMNs: 45005 and 45012
Initial AT+CEREG?: 0,3, registration denied
Initial PDP context 1 APN: literal placeholder "YourAPN"
After cleanup AT+CNMP?: 38, LTE only
After cleanup AT+CEREG?: 0,1, home network registered
After cleanup AT+CGATT?: 1
After cleanup AT+CPSI?: LTE CAT-M1, Online, 450-05, Band 5
SMS transmission: pending controlled single-SMS test
```

Therefore, no evidence currently shows a Cat-1 versus Cat-M protocol mismatch.
Both tests used the SIM7080 firmware family and Cat-M mode. The same SIM
registered on the Stamp after its local modem configuration was normalized.
The earlier IMEI/OMD/account hypothesis is therefore not supported by the final
test result.

Source records:

```text
260708_hardware_bringup_log.md
260709_lte_sms_integrated_firmware_log.md
```

## 11. Carrier Inquiry Checklist

Contact the company that actually issued the SIM. If the line is an SKT-network
MVNO line, its MVNO customer center must check the subscription and device
authorization first; the SKT retail customer center may not be able to modify
an MVNO account.

Prepare:

```text
Subscriber phone number
SIM ICCID from AT+CCID
SIM IMSI from AT+CIMI (starts with 45005)
Stamp modem IMEI from AT+CGSN
Module: M5Stack Stamp CatM, SIMCom SIM7080G
Mode: LTE Cat-M1, CNMP=38, CMNB=1
Supported Korean LTE bands used by the module: B1/B3/B5
```

Suggested Korean inquiry:

```text
SKT망으로 개통한 유심을 SIMCom SIM7080G 기반 LTE Cat-M1 모듈에서
사용하려고 합니다. 같은 유심은 기존 SIM7080 개발보드에서 SKT 45005에
등록되어 SMS 송신까지 성공했지만, 새 Stamp CatM 모듈에서는 CPIN READY,
CSQ 23~31, SKT 45005/45012 검색까지 정상인데 CEREG 0,3으로 등록이
거절됩니다.

새 모듈 IMEI를 OMD 또는 M2M/LTE 모뎀 단말로 등록해야 하는지,
유심보호·기기변경 제한이나 IMEI 화이트리스트가 걸려 있는지,
현재 요금제가 LTE Cat-M1 단말과 SMS를 허용하는지 확인 부탁드립니다.
망 로그에 남은 registration denied의 reject cause도 확인 가능하면
부탁드립니다. 이 회선은 45005와 45012 중 어느 PLMN으로 등록해야 하며,
등록 후 사용할 APN도 알려주세요.
```

Questions that require an explicit carrier answer:

1. Is LTE Cat-M1 service allowed on the current subscription and SIM?
2. Does the Stamp IMEI require OMD, M2M, or LTE-modem registration?
3. Is USIM protection, terminal-change blocking, or an IMEI allowlist active?
4. What network reject cause was recorded for `CEREG stat 3`?
5. Should the device register on PLMN `45005` or IoT PLMN `45012`?
6. Can the current line send SMS from a Cat-M1 modem?
7. Which APN should be used after successful registration?

## 12. SKT Contact Information Checked on 2026-07-31

```text
SKT mobile: 114, free
Other phones: 080-011-6000, free
General number: 1599-0011, paid
Human counselor: weekdays 09:00-18:00
Lunch 12:00-13:00: emergency specialist service only
AI/ARS: 24 hours
```

The official T world LTE-M pages state that Cat-M1 and Cat.1 special-purpose
devices are supported by LTE-M plans and that device/plan inquiries are handled
through SKT branches, the customer center, or an IoT/M2M specialist agency.

Official references:

- https://m.tworld.co.kr/customer/svc-info/service/detail?code=C00038
- https://m.tworld.co.kr/product/callplan?prod_id=NA00005661
- https://m.tworld.co.kr/customer/svc-info/service/detail?code=C00023

Because the tested SIM was opened through an SKT-network MVNO, the first call
should be to the MVNO that issued the line. SKT's customer center can explain
network requirements, but it may be unable to change an MVNO subscription or
register its device profile directly.

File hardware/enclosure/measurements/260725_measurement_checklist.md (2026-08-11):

# 260725 Case Measurement Checklist

Measure with calipers where possible. If exact measurement is difficult, record estimate and photo.

## Wrist / Wear

- Wrist circumference:
- Wrist top flat-ish width:
- Desired wearable body max width:
- Desired wearable body max length:
- Comfortable max thickness target:
- Strap width target:

## Modules

### ESP32-C3 SuperMini

- Board length:
- Board width:
- Max height including USB-C:
- USB-C side clearance needed:
- Header/wire height:

### M5Stack Stamp CatM S003

- Body length:
- Body width:
- Max height:
- SIM access needed: yes/no
- Antenna connector/cable exit direction:
- 5V/3V3/GND/TX/RX pad side direction:

### Beitian BE-220

- Body length:
- Body width:
- Height:
- Connector/cable exit direction:
- Patch antenna face direction:

### Battery TW-602035

- Length:
- Width:
- Thickness:
- Wire exit direction:
- Connector retained or cut:

### MAX30102

- Board length:
- Board width:
- Height:
- Optical sensor window position from board edges:
- Skin contact opening diameter/size target:
- Wire exit direction:

### TMP117

- Board length:
- Board width:
- Height:
- Sensor chip position from board edges:
- Wire exit direction:

### Buzzer / Button

- Buzzer diameter:
- Buzzer height:
- Button length/width/height:
- Desired button access direction:

## Design Decisions

- One-piece case or base+lid:
- Screws / snap fit / tape / zip tie / heat-shrink / adhesive:
- Sensor side material:
- GPS top cover thickness target:
- Presentation render color:

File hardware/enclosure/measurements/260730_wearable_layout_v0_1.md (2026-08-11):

# 260730 Wearable Mechanical Layout v0.1

Date: 2026-07-30

Status: M4 working layout

Basis:

- Wrist circumference: 165 mm
- Wrist top straight width: 55 mm
- Main enclosure length target: 40 mm maximum
- Main enclosure width target: less than 50 mm
- Component envelopes from `260730_component_dimension_synthesis.md`

## 1. Architecture

Use three mechanically separated regions connected by flexible wiring:

```text
Outer wrist:
  Main electronics pod
  Separate BE-220 GPS pod
  LTE film antenna fixed flat along the outward-facing strap

Inner wrist:
  Combined MAX30102 + TMP117 sensor bar
```

Do not put every module in one rigid enclosure.

## 2. Main Electronics Pod

Contents:

- Stamp CatM S003
- ESP32-C3 SuperMini
- selected Li-Po battery
- 3 V active buzzer
- recessed trigger switch
- wiring junctions

Packing concept:

```text
Plan view:

  +--------------------+--------------------------+
  | Stamp CatM         | ESP32-C3 zone            |
  | 20.6 x 30.9        | battery stacked over ESP |
  |                    |                          |
  +--------------------+--------------------------+
```

The Stamp CatM is rotated so its 20.6 mm envelope is across the case and its
30.9 mm envelope runs along the case. The ESP32 and battery occupy the adjacent
region. The battery must not sit above the Stamp CatM.

First-pass outer target:

```text
With 150/220 mAh battery:
  approximately 49.5 x 33.5 x 14 to 15.5 mm

With 380 mAh battery:
  approximately 47 x 39 x 14.5 to 15.5 mm
```

Both versions remain within the current 50 x 40 mm plan limit. Final Z depends
on insulation, wire routing, and lid retention.

Required access:

- ESP32 USB-C side opening
- removable lid for SIM and wiring access
- recessed trigger on top
- buzzer openings on a side or lid
- IPEX coax exit toward the LTE antenna strap

## 3. GPS Pod

Contents:

- BE-220 only
- 4-wire power/UART cable

First-pass outer target:

```text
approximately 25 x 23 x 8 mm
plus a provisional 8 mm cable-exit zone
```

Placement:

- ceramic patch faces outward
- no battery, metal screw, or LTE antenna directly above it
- mount on the strap adjacent to, but mechanically separate from, the main pod
- verify the 4-pin connector allowance after delivery

## 4. Inner Sensor Bar

Contents:

- MAX30102
- TMP117 breakout
- shared 3V3, GND, SDA, and SCL harness

Packing:

```text
[ MAX30102 21.6 x 16.6 ] [ TMP117 26.0 x 18.4 ]
```

First-pass outer target:

```text
approximately 50 x 21 x 7.5 mm
```

Skin interface:

- MAX30102: centered 4 x 7 mm optical opening with a black light-blocking ring
- TMP117: centered approximately 4 x 4 mm thermal contact island
- board connectors and solder joints remain recessed inside the pod
- only the optical/thermal contact regions approach the skin plane
- use a soft gasket or TPU/silicone contact feature to stabilize pressure

The sensor bar connects to the main pod with one flexible 4-wire I2C harness.

## 5. Strap

Working width:

```text
22 mm
```

Reasons:

- accommodates the 20 mm-wide LTE film antenna
- carries the 4-wire sensor harness
- remains narrow relative to the 50 mm main body
- matches a common watch-strap class

LTE antenna placement:

- 50 x 20 x less than 1 mm film body
- adhere flat to the outward-facing strap
- keep away from the GPS patch
- route coax to the Stamp CatM without a sharp kink

## 6. Battery Decision Gate

Test order after delivery:

1. 220 mAh
2. 150 mAh
3. use the already proven 380 mAh if either smaller cell is unstable

Pass sequence:

```text
Battery-only power
-> Stamp CatM boot
-> network registration
-> BE-220 GPS operation
-> MAX30102 and TMP117 read
-> SMS transmission
-> no ESP reset or modem UART loss
```

## 7. Open Checks Before CAD Freeze

- Confirm actual 150/220 mAh pouch dimensions after delivery.
- Confirm BE-220 plug and cable-exit dimensions after delivery.
- Select a trigger switch within the reserved 8 x 8 x 6 mm envelope.
- Decide lid retention: two screws, four screws, or tape-assisted snap fit.
- Decide whether the inner sensor bar uses a printed TPU contact insert or a
  separate soft gasket.

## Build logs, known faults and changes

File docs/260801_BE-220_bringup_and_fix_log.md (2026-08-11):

# BE-220 GPS Bring-Up and Fix Test Log

Date: 2026-08-01

## 1. Objective

Complete the deferred incoming inspection, physical measurement, UART bring-up,
NMEA validation, and outdoor position-fix test for the delivered Beitian BE-220
GPS module before resuming the wearable enclosure work.

## 2. Hardware and Wiring

- MCU: ESP32-C3 SuperMini
- GPS: Beitian BE-220
- MCU power/debug: USB from notebook
- GPS supply: ESP32-C3 `5V` and `GND`
- GPS UART: 3.3 V TTL

```text
BE-220 GND -> ESP32-C3 GND
BE-220 TX  -> ESP32-C3 GPIO6 (GPS RX)
BE-220 RX  -> ESP32-C3 GPIO7 (GPS TX)
BE-220 VCC -> ESP32-C3 5V
```

The module pin order in the saved vendor reference is `GND, TX, RX, VCC` from
pin 1 through pin 4. The reference image is stored at:

```text
03_references/260801_BE-220/260801_BE-220_pinout_and_led_reference.webp
```

## 3. Physical Inspection

Measured maximum envelope:

```text
20 x 22 x 6.25 mm
```

The nominal model height may be treated as 6 mm, but 6.25 mm is the measured
worst-case height to use for fit validation. The ceramic antenna and receiver
occupy nearly the complete board area.

## 4. Baud-Rate Diagnosis

The product reference stated a default UART rate of 38400 baud. Initial reads at
38400 produced incoming bytes but not readable NMEA text. A firmware `GPSRAW`
command exposed the malformed stream, so the earlier assumption that any byte
count implied valid NMEA was rejected.

The added `GPSPROBE` command tested common rates. Relevant results:

```text
38400 baud: 62% printable, no NMEA sentence delimiters
115200 baud: 100% printable, 31 '$' delimiters, 31 complete lines
```

Conclusion: this physical BE-220 unit is configured for 115200 baud despite the
38400-baud vendor listing. The `esp32c3_supermini` firmware configuration was
changed to `GPS_BAUD=115200`.

## 5. NMEA and Outdoor Fix Results

At 115200 baud the receiver emitted valid NMEA sentences including `GNRMC`,
`GNGGA`, `GNGSA`, `GPGSV`, `GAGSV`, `GBGSV`, and `GNGLL`.

Representative outdoor result:

```text
RMC status: A (valid)
GGA fix quality: 1
GSA mode: 3 (3D)
Satellites used: 6
HDOP: 2.32
Altitude: approximately 68 m
Latitude: 35.821526
Longitude: 128.755417
NMEA checksum failures: 0
```

The integrated TinyGPSPlus parser also returned a valid latitude and longitude.
The parser originally returned immediately after the RMC location field and
therefore printed satellite count and HDOP as zero before the following GGA
sentence arrived. The success condition was updated to wait for valid location,
satellite, and HDOP fields.

After the successful outdoor fix, the setup was moved back indoors. A subsequent
check then returned zero satellites and no fix. This was an expected indoor signal
loss, not intermittent module behavior or a regression caused by the firmware
upload.

## 6. Firmware Changes

- Corrected the SuperMini external GPS baud rate from 38400 to 115200.
- Added `GPSRAW [seconds]` for direct NMEA inspection.
- Added `GPSPROBE` for UART baud-rate detection.
- Changed GPS success logging to wait for GGA quality data.
- Extended no-fix logging with satellite count and HDOP.

## 7. Result

```text
Physical inspection: PASS
5 V power: PASS
UART electrical connection: PASS
Baud-rate identification: PASS (115200)
Readable NMEA stream: PASS
Outdoor 3D position fix: PASS
Firmware coordinate parsing: PASS
PPS LED visual confirmation: not recorded during this test
```

The temporary `ERROR` state visible in some serial logs was caused by the other
I2C sensors not being connected during this GPS-only test. It is unrelated to the
BE-220 result.

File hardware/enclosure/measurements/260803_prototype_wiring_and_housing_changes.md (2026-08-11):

# 260803 Prototype Wiring And Housing Changes

Date: 2026-08-03

Status: wiring-layout freeze before final enclosure printing

## 1. Recommended Physical Order

Arrange the rigid housings in this order around the wrist:

```text
Stamp CatM -- ESP32-C3 + 220 mAh battery -- BE-220 GPS -- MAX30102 -- TMP117
```

Reasons:

- The Stamp CatM high-current power path remains short.
- The sensor bus crosses only the GPS housing before reaching MAX30102, while
  TMP117 remains farthest from LTE and main-electronics heat.
- The GPS housing can carry the sensor bus through without placing the TMP117
  next to the modem.
- The buzzer remains inside the ESP32-C3/battery housing.

## 2. Fixed ESP32-C3 SuperMini Pin Map

Use the tested `esp32c3_supermini` firmware environment.

| Function | ESP32-C3 pin | Remote connection |
|---|---:|---|
| I2C SDA | GPIO8 | MAX30102 SDA and TMP117 SDA |
| I2C SCL | GPIO9 | MAX30102 SCL and TMP117 SCL |
| LTE RX | GPIO20 | Stamp CatM TX |
| LTE TX | GPIO21 | Stamp CatM RX |
| GPS RX | GPIO6 | BE-220 TX |
| GPS TX | GPIO7 | BE-220 RX |
| Buzzer | GPIO10 | Active buzzer positive/signal |
| Sensor supply | 3V3 | MAX30102 VIN and TMP117 VIN |
| Common return | GND | All modules |

The delivered BE-220 was experimentally identified as `115200 baud`, even
though the vendor listing stated `38400 baud`.

## 3. Module Wiring

### Stamp CatM

```text
Stamp 5V  -> dedicated modem power pair from the main power junction
Stamp GND -> common GND
Stamp TX  -> ESP32-C3 GPIO20
Stamp RX  -> ESP32-C3 GPIO21
Stamp 3V3 -> no external connection
Stamp RF  -> LTE antenna coax
```

Do not externally connect both the Stamp `5V` and `3V3` pins. The board's
onboard 3.3 V rail was previously measured while the board was supplied from
5 V.

The Stamp-based battery-only full-system test is still pending in the existing
test log. Keep this power pair detachable until the final supply method passes
boot, network registration, and SMS transmission from the 220 mAh battery.

### BE-220 GPS

```text
BE-220 VCC -> main raw power rail
BE-220 GND -> common GND
BE-220 TX  -> ESP32-C3 GPIO6
BE-220 RX  -> ESP32-C3 GPIO7
```

The module input specification is 3.6-5.5 V. The current physical unit passed
NMEA and outdoor-fix testing when powered from the ESP USB 5 V rail. Battery
operation must be repeated after the final harness is assembled.

### MAX30102 And TMP117

Both sensors share one short four-wire I2C trunk:

```text
ESP 3V3   -> MAX30102 VIN -> TMP117 VIN
ESP GND   -> MAX30102 GND -> TMP117 GND
ESP GPIO8 -> MAX30102 SDA -> TMP117 SDA
ESP GPIO9 -> MAX30102 SCL -> TMP117 SCL
```

Unused pins:

```text
MAX30102 INT, RD, IRD -> not connected
TMP117 INT            -> not connected
TMP117 ADDR           -> retain breakout default
```

The physical bus order is ESP -> MAX30102 -> TMP117. Make the branch inside the
MAX30102 housing using insulated solder joints or a compact four-line splice.

### Active Buzzer

Keep the buzzer local to the ESP/battery housing:

```text
Buzzer + -> GPIO10
Buzzer - -> GND
```

## 4. Power Junction

Use a parallel/star junction inside the ESP/battery housing. Do not daisy-chain
the supply through module pads.

```text
220 mAh Li-Po connector
        |
        +-- ESP32-C3 5V/GND
        +-- Stamp CatM power pair
        +-- BE-220 VCC/GND

ESP32-C3 regulated 3V3
        +-- MAX30102 VIN
        +-- TMP117 VIN
```

The same two-pin battery connector is the master disconnect and external-charge
interface. Charging requires the battery to be physically disconnected from the
wearable and connected to the separate charger. Do not expose bare charging
contacts.

Use the purchased two-pin harness for battery and modem power. Use the purchased
SH1.0 four-wire harness for I2C and UART signals. Keep the modem power pair as
short as practical.

## 5. Housing Changes Before Final Print

### ESP32-C3 And Battery Housing

- Add a recessed opening for the two-pin battery disconnect connector.
- Add an internal strain-relief channel immediately after the battery splice.
- Add one four-wire exit toward the Stamp housing.
- Add two cable lanes toward the GPS/sensor side: GPS UART/raw power and the
  sensor 3V3/I2C trunk.
- Keep all splices above an insulated floor and away from the Li-Po pouch.
- Retain USB-C access for firmware upload and debugging.

### Stamp CatM Housing

- Add one four-wire entry for power, GND, TX, and RX.
- Add a rounded coax exit independent of the electrical-wire opening.
- Provide at least a 10 mm coax bend radius and no hinge pinch point.
- Keep the SIM and antenna connector serviceable.

### GPS Housing

- Add one entry facing the ESP housing for VCC, GND, TX, RX, and the sensor bus.
- Add one four-wire exit facing the MAX30102 housing for 3V3, GND, SDA, and SCL.
- Use separate shallow channels for GPS wiring and the passing sensor trunk.
- Keep every wire below the ceramic patch perimeter and do not cross its top.

### MAX30102 Housing

- Add a four-wire input from the GPS/ESP direction.
- Add a four-wire output toward TMP117.
- Add a protected internal splice pocket away from the optical package.
- Do not route wiring across the optical opening or skin-contact frame.

### TMP117 Housing

- Add one four-wire input only; this is the end of the I2C trunk.
- Place the wire strain relief away from the central thermal-contact island.
- Avoid a thick wire bundle directly behind the temperature sensor.

## 6. Hinge-Crossing Rules

- Do not route wires through a hinge pin or between knuckle end faces.
- Place each cable exit beside the pivot axis, toward the outward-facing surface.
- Provide a free loop of 5-8 mm between adjacent housings.
- Use rounded cable-slot edges with at least `R1.0 mm`.
- Recommended open cable notch for one four-wire harness: approximately
  `5.0 x 2.5 mm`; verify against the actual harness before printing.
- Where two harnesses pass the same joint, use two separate notches instead of
  compressing eight wires into one slot.
- Exercise the full hinge angle before fixing the wires with Kapton tape.
- Add strain relief at least 5 mm inside each housing so bending occurs in the
  free loop, not at a solder joint.

## 7. Assembly And Test Order

1. Print a cable-notch and hinge coupon before the complete housing set.
2. Route unpowered harnesses and check the complete hinge range.
3. Verify no pinching, insulation damage, or sensor-face obstruction.
4. Connect battery power with every module unplugged.
5. Add ESP32-C3 and verify regulated 3.3 V.
6. Add MAX30102 and TMP117 and run `I2CSCAN` and `MEASURE`.
7. Add BE-220 and run `GPSRAW`, `GPSPROBE`, and outdoor `GPS` fix.
8. Add Stamp CatM and verify `AT`, network registration, and one controlled SMS.
9. Disconnect USB and repeat the complete sequence from the 220 mAh battery.

Do not permanently close the housings until step 9 passes.

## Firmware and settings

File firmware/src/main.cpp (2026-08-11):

#include <Arduino.h>
#include <TinyGPSPlus.h>
#include <Wire.h>
#include "pins.h"

HardwareSerial lteSerial(1);
HardwareSerial gpsSerial(0);
TinyGPSPlus gpsParser;
bool lteSerialStarted = false;
bool gpsSerialStarted = false;
volatile uint32_t lteRxEdgeCount = 0;

void IRAM_ATTR countLteRxEdge() {
  lteRxEdgeCount++;
}

enum class SystemState {
  BOOT,
  NOT_WORN,
  NORMAL,
  SUSPECT,
  ALARM,
  EMERGENCY_READY,
  ERROR
};

enum class BuzzerMode {
  OFF,
  WORN_TONE,
  ALARM_PATTERN,
  ERROR_PATTERN
};

struct SensorSnapshot {
  float tempC = NAN;
  uint32_t red = 0;
  uint32_t ir = 0;
  bool tmpOk = false;
  bool maxOk = false;
  bool worn = false;
};

struct LteStatus {
  bool atOk = false;
  bool simReady = false;
  bool registered = false;
  bool attached = false;
  int csq = -1;
  String operatorName;
};

struct LocationFix {
  bool ok = false;
  float lat = NAN;
  float lon = NAN;
};

constexpr uint32_t SENSOR_SAMPLE_MS = 100;
constexpr uint32_t TEMP_SAMPLE_MS = 1000;
constexpr uint32_t STATUS_PRINT_MS = 1000;
constexpr uint32_t LTE_CHECK_MS = 60000;
constexpr uint32_t SUSPECT_CONFIRM_MS = 10000;
constexpr uint32_t ALARM_COUNTDOWN_MS = 30000;

constexpr uint32_t WEAR_ON_IR_THRESHOLD = 80000;
constexpr uint32_t WEAR_OFF_IR_THRESHOLD = 60000;
constexpr uint8_t WEAR_CONFIRM_COUNT = 3;

constexpr float TEMP_SUSPECT_C = 38.0f;

SystemState state = SystemState::BOOT;
BuzzerMode buzzerMode = BuzzerMode::OFF;
SensorSnapshot sensors;
LteStatus lteStatus;

bool max30102Ready = false;
uint8_t wornHighCount = 0;
uint8_t wornLowCount = 0;
uint8_t tmpFailCount = 0;
uint8_t maxFailCount = 0;

uint32_t lastSensorMs = 0;
uint32_t lastTempMs = 0;
uint32_t lastStatusMs = 0;
uint32_t lastLteCheckMs = 0;
uint32_t suspectStartMs = 0;
uint32_t alarmStartMs = 0;
uint32_t buzzerTickMs = 0;
bool buzzerOutput = false;

String serialLine;
bool standaloneTestRunning = false;
bool triggerWasLow = false;
uint32_t triggerLowSince = 0;
bool batteryTestRunning = false;
bool batteryTriggerWasLow = false;
uint32_t batteryTriggerLowSince = 0;

void pollSerialCommands();
void updateSensors();
void updateStateMachine();
void updateBuzzer();
void handleStandaloneTrigger();
void handleBatteryTestTrigger();
void beep(uint16_t durationMs);
void progressBeep(uint16_t durationMs = 45);
void pulseModemPowerKeyHigh(uint16_t highMs);
bool probeLteBaud(uint32_t baud);
void updateLteStatus(bool verbose);

const char *stateName(SystemState value) {
  switch (value) {
    case SystemState::BOOT: return "BOOT";
    case SystemState::NOT_WORN: return "NOT_WORN";
    case SystemState::NORMAL: return "NORMAL";
    case SystemState::SUSPECT: return "SUSPECT";
    case SystemState::ALARM: return "ALARM";
    case SystemState::EMERGENCY_READY: return "EMERGENCY_READY";
    case SystemState::ERROR: return "ERROR";
  }
  return "UNKNOWN";
}

void setState(SystemState next) {
  if (state == next) return;
  Serial.printf("[state] %s -> %s\n", stateName(state), stateName(next));
  state = next;

  if (next == SystemState::SUSPECT) {
    suspectStartMs = millis();
  } else if (next == SystemState::ALARM) {
    alarmStartMs = millis();
  }
}

void setBuzzerMode(BuzzerMode next) {
  if (buzzerMode == next) return;
  buzzerMode = next;
  buzzerTickMs = 0;
}

bool i2cDevicePresent(uint8_t address) {
  Wire.beginTransmission(address);
  return Wire.endTransmission() == 0;
}

void scanI2cBus() {
  Serial.println("[i2c] scanning...");
  uint8_t found = 0;
  for (uint8_t addr = 1; addr < 127; addr++) {
    if (i2cDevicePresent(addr)) {
      Serial.printf("[i2c] found 0x%02X\n", addr);
      found++;
    }
  }
  if (found == 0) {
    Serial.println("[i2c] no devices found");
  }
}

bool readRegister16(uint8_t address, uint8_t reg, uint16_t &value) {
  Wire.beginTransmission(address);
  Wire.write(reg);
  if (Wire.endTransmission(false) != 0) return false;
  if (Wire.requestFrom(static_cast<int>(address), 2) != 2) return false;
  value = (static_cast<uint16_t>(Wire.read()) << 8) | Wire.read();
  return true;
}

bool writeRegister16(uint8_t address, uint8_t reg, uint16_t value) {
  Wire.beginTransmission(address);
  Wire.write(reg);
  Wire.write(static_cast<uint8_t>(value >> 8));
  Wire.write(static_cast<uint8_t>(value & 0xFF));
  return Wire.endTransmission() == 0;
}

void monitorIna219Power(uint16_t durationSeconds) {
  constexpr uint8_t INA219_ADDR = 0x40;
  constexpr float SHUNT_OHMS = 0.1f;

  if (!i2cDevicePresent(INA219_ADDR)) {
    Serial.println("[ina219] not found at 0x40");
    return;
  }

  // 32 V range, 320 mV shunt range, 12-bit continuous shunt and bus readings.
  if (!writeRegister16(INA219_ADDR, 0x00, 0x399F)) {
    Serial.println("[ina219] configuration failed");
    return;
  }

  delay(5);
  Serial.printf("[ina219] monitoring %u s; assuming R100 (0.1 ohm) shunt\n",
                durationSeconds);
  Serial.println("[ina219] ms,load_V,source_V,current_mA,shunt_mV,overflow");

  uint32_t startMs = millis();
  uint32_t samples = 0;
  float minLoadV = 1000.0f;
  float maxLoadV = -1000.0f;
  float minCurrentMa = 1000000.0f;
  float maxCurrentMa = -1000000.0f;
  double sumLoadV = 0.0;
  double sumCurrentMa = 0.0;

  while (millis() - startMs < static_cast<uint32_t>(durationSeconds) * 1000UL) {
    uint16_t shuntRawUnsigned = 0;
    uint16_t busRaw = 0;
    if (!readRegister16(INA219_ADDR, 0x01, shuntRawUnsigned) ||
        !readRegister16(INA219_ADDR, 0x02, busRaw)) {
      Serial.println("[ina219] read failed");
      delay(100);
      continue;
    }

    int16_t shuntRaw = static_cast<int16_t>(shuntRawUnsigned);
    float shuntMv = shuntRaw * 0.01f;
    float loadV = (busRaw >> 3) * 0.004f;
    float currentMa = (shuntMv / 1000.0f) / SHUNT_OHMS * 1000.0f;
    float sourceV = loadV + shuntMv / 1000.0f;
    bool overflow = (busRaw & 0x01) != 0;

    minLoadV = min(minLoadV, loadV);
    maxLoadV = max(maxLoadV, loadV);
    minCurrentMa = min(minCurrentMa, currentMa);
    maxCurrentMa = max(maxCurrentMa, currentMa);
    sumLoadV += loadV;
    sumCurrentMa += currentMa;
    samples++;

    Serial.printf("[ina219] %lu,%.3f,%.3f,%.1f,%.3f,%u\n",
                  millis() - startMs, loadV, sourceV, currentMa, shuntMv,
                  overflow);
    delay(100);
  }

  if (samples == 0) {
    Serial.println("[ina219] no valid samples");
    return;
  }

  Serial.printf(
      "[ina219-summary] samples=%lu load_V[min=%.3f avg=%.3f max=%.3f] "
      "current_mA[min=%.1f avg=%.1f max=%.1f]\n",
      samples, minLoadV, static_cast<float>(sumLoadV / samples), maxLoadV,
      minCurrentMa, static_cast<float>(sumCurrentMa / samples), maxCurrentMa);
}

bool writeRegister8(uint8_t address, uint8_t reg, uint8_t value) {
  Wire.beginTransmission(address);
  Wire.write(reg);
  Wire.write(value);
  return Wire.endTransmission() == 0;
}

bool readRegister8(uint8_t address, uint8_t reg, uint8_t &value) {
  Wire.beginTransmission(address);
  Wire.write(reg);
  if (Wire.endTransmission(false) != 0) return false;
  if (Wire.requestFrom(static_cast<int>(address), 1) != 1) return false;
  value = Wire.read();
  return true;
}

bool readTmp117Celsius(float &celsius) {
  uint16_t raw = 0;
  if (!readRegister16(TMP117_ADDR, 0x00, raw)) return false;
  float value = static_cast<int16_t>(raw) * 0.0078125f;
  if (value < -40.0f || value > 125.0f) return false;
  celsius = value;
  return true;
}

bool readTmp117CelsiusReliable(float &celsius, uint8_t attempts = 6) {
  for (uint8_t i = 0; i < attempts; i++) {
    if (readTmp117Celsius(celsius)) return true;
    delay(60);
  }
  if (!isnan(sensors.tempC)) {
    celsius = sensors.tempC;
    return true;
  }
  return false;
}

bool readMax30102PartId(uint8_t &partId) {
  Wire.beginTransmission(MAX30102_ADDR);
  Wire.write(0xFF);
  if (Wire.endTransmission(false) != 0) return false;
  if (Wire.requestFrom(static_cast<int>(MAX30102_ADDR), 1) != 1) return false;
  partId = Wire.read();
  return true;
}

bool initMax30102() {
  if (!writeRegister8(MAX30102_ADDR, 0x09, 0x40)) return false;
  delay(100);

  uint8_t mode = 0xFF;
  for (uint8_t i = 0; i < 10; i++) {
    if (readRegister8(MAX30102_ADDR, 0x09, mode) && (mode & 0x40) == 0) break;
    delay(50);
  }

  if (!writeRegister8(MAX30102_ADDR, 0x04, 0x00)) return false;
  if (!writeRegister8(MAX30102_ADDR, 0x05, 0x00)) return false;
  if (!writeRegister8(MAX30102_ADDR, 0x06, 0x00)) return false;
  if (!writeRegister8(MAX30102_ADDR, 0x08, 0x4F)) return false;
  if (!writeRegister8(MAX30102_ADDR, 0x09, 0x03)) return false;
  if (!writeRegister8(MAX30102_ADDR, 0x0A, 0x27)) return false;
  if (!writeRegister8(MAX30102_ADDR, 0x0C, 0x24)) return false;
  if (!writeRegister8(MAX30102_ADDR, 0x0D, 0x24)) return false;
  return true;
}

bool readMax30102Sample(uint32_t &red, uint32_t &ir) {
  Wire.beginTransmission(MAX30102_ADDR);
  Wire.write(0x07);
  if (Wire.endTransmission(false) != 0) return false;
  if (Wire.requestFrom(static_cast<int>(MAX30102_ADDR), 6) != 6) return false;

  red = (static_cast<uint32_t>(Wire.read()) << 16) |
        (static_cast<uint32_t>(Wire.read()) << 8) |
        Wire.read();
  ir = (static_cast<uint32_t>(Wire.read()) << 16) |
       (static_cast<uint32_t>(Wire.read()) << 8) |
       Wire.read();
  red &= 0x3FFFF;
  ir &= 0x3FFFF;
  return true;
}

void updateWearState(uint32_t ir) {
  bool nextWorn = sensors.worn;

  if (ir >= WEAR_ON_IR_THRESHOLD) {
    wornHighCount = min<uint8_t>(WEAR_CONFIRM_COUNT, wornHighCount + 1);
    wornLowCount = 0;
  } else if (ir <= WEAR_OFF_IR_THRESHOLD) {
    wornLowCount = min<uint8_t>(WEAR_CONFIRM_COUNT, wornLowCount + 1);
    wornHighCount = 0;
  }

  if (!sensors.worn && wornHighCount >= WEAR_CONFIRM_COUNT) {
    nextWorn = true;
  } else if (sensors.worn && wornLowCount >= WEAR_CONFIRM_COUNT) {
    nextWorn = false;
  }

  if (nextWorn != sensors.worn) {
    sensors.worn = nextWorn;
    Serial.printf("[wear] %s ir=%lu\n", sensors.worn ? "detected" : "removed", ir);
  }
}

String readLteResponse(uint32_t timeoutMs) {
  String response;
  const uint32_t start = millis();
  while (millis() - start < timeoutMs) {
    while (lteSerial.available()) {
      response += static_cast<char>(lteSerial.read());
    }
    delay(5);
  }
  response.trim();
  return response;
}

String sendLteCommand(const char *command, uint32_t timeoutMs = 1500) {
  if (!lteSerialStarted) {
    lteSerial.begin(115200, SERIAL_8N1, LTE_RX_PIN, LTE_TX_PIN);
    lteSerialStarted = true;
    delay(100);
  }
  Serial.printf("[lte] >> %s\n", command);
  lteSerial.print(command);
  lteSerial.print("\r\n");
  String response = readLteResponse(timeoutMs);
  Serial.printf("[lte] << %s\n", response.length() ? response.c_str() : "no response");
  return response;
}

bool waitForLtePrompt(uint32_t timeoutMs) {
  const uint32_t start = millis();
  String response;
  while (millis() - start < timeoutMs) {
    while (lteSerial.available()) {
      char c = static_cast<char>(lteSerial.read());
      response += c;
      if (c == '>') {
        Serial.printf("[lte] << %s\n", response.c_str());
        return true;
      }
    }
    delay(5);
  }
  response.trim();
  Serial.printf("[lte] << prompt timeout%s%s\n", response.length() ? ": " : "", response.c_str());
  return false;
}

bool sendSms(const char *phoneNumber, const char *message) {
  if (!lteStatus.registered) {
    Serial.println("[sms] blocked: LTE is not registered");
    return false;
  }

  sendLteCommand("AT+CMGF=1", 3000);
  sendLteCommand("AT+CSCS=\"GSM\"", 3000);

  Serial.printf("[sms] sending to %s\n", phoneNumber);
  lteSerial.print("AT+CMGS=\"");
  lteSerial.print(phoneNumber);
  lteSerial.print("\"\r\n");

  if (!waitForLtePrompt(10000)) {
    Serial.println("[sms] failed: no prompt");
    return false;
  }

  lteSerial.print(message);
  lteSerial.write(0x1A);
  String response = readLteResponse(60000);
  Serial.printf("[sms] response: %s\n", response.length() ? response.c_str() : "no response");
  return response.indexOf("OK") >= 0 || response.indexOf("+CMGS") >= 0;
}

bool modemAtOk() {
  String response = sendLteCommand("AT", 1200);
  return response.indexOf("OK") >= 0;
}

bool waitForModemAt(const char *label, uint8_t attempts, uint32_t intervalMs) {
  for (uint8_t i = 1; i <= attempts; i++) {
    Serial.printf("[standalone] %s AT check %u/%u\n", label, i, attempts);
    lteSerial.end();
    delay(80);
    lteSerial.begin(115200, SERIAL_8N1, LTE_RX_PIN, LTE_TX_PIN);
    lteSerialStarted = true;
    delay(120);
    if (modemAtOk()) {
      Serial.printf("[standalone] modem responds during %s wait\n", label);
      return true;
    }
    if (i % 5 == 0) progressBeep(25);
    delay(intervalMs);
  }
  return false;
}

bool ensureModemAwake() {
  Serial.println("[standalone] quick AT check before PWRK");
  if (waitForModemAt("pre-pwrk", 2, 500)) {
    return true;
  }

  Serial.println("[standalone] quick direct AT failed; probing UART before PWRK");
  if (probeLteBaud(115200)) {
    updateLteStatus(true);
    return lteStatus.atOk;
  }

  Serial.println("[standalone] no AT response; pulsing PWRK HIGH for 1000 ms");
  pulseModemPowerKeyHigh(1000);
  Serial.println("[standalone] waiting 7 seconds for modem boot");
  delay(7000);

  if (waitForModemAt("post-pwrk", 8, 1500)) {
    return true;
  }

  Serial.println("[standalone] post-PWRK direct AT failed; probing UART again");
  if (probeLteBaud(115200)) {
    updateLteStatus(true);
    return lteStatus.atOk;
  }

  Serial.println("[standalone] modem did not respond");
  return false;
}

int parseCsq(const String &response) {
  int marker = response.indexOf("+CSQ:");
  if (marker < 0) return -1;
  int comma = response.indexOf(',', marker);
  if (comma < 0) return -1;
  String value = response.substring(marker + 5, comma);
  value.trim();
  return value.toInt();
}

bool responseHasRegistration(const String &response) {
  return response.indexOf(",1") >= 0 || response.indexOf(",5") >= 0;
}

bool responseHasGnssCoordinate(const String &response) {
  int marker = response.indexOf("+CGNSINF:");
  if (marker < 0) return false;

  int lineEnd = response.indexOf('\n', marker);
  String line = lineEnd >= 0 ? response.substring(marker, lineEnd) : response.substring(marker);
  line.trim();

  int colon = line.indexOf(':');
  if (colon < 0) return false;

  String payload = line.substring(colon + 1);
  payload.trim();

  String fields[6];
  int fieldIndex = 0;
  int start = 0;
  while (fieldIndex < 6) {
    int comma = payload.indexOf(',', start);
    if (comma < 0) {
      fields[fieldIndex++] = payload.substring(start);
      break;
    }
    fields[fieldIndex++] = payload.substring(start, comma);
    start = comma + 1;
  }

  if (fieldIndex < 5) return false;

  fields[0].trim();
  fields[3].trim();
  fields[4].trim();
  if (fields[0] != "1" || fields[3].length() == 0 || fields[4].length() == 0) return false;

  float lat = fields[3].toFloat();
  float lon = fields[4].toFloat();
  return lat >= -90.0f && lat <= 90.0f && lon >= -180.0f && lon <= 180.0f;
}

LocationFix parseGnssCoordinate(const String &response) {
  LocationFix fix;
  int marker = response.indexOf("+CGNSINF:");
  if (marker < 0) return fix;

  int lineEnd = response.indexOf('\n', marker);
  String line = lineEnd >= 0 ? response.substring(marker, lineEnd) : response.substring(marker);
  line.trim();

  int colon = line.indexOf(':');
  if (colon < 0) return fix;

  String payload = line.substring(colon + 1);
  payload.trim();

  String fields[6];
  int fieldIndex = 0;
  int start = 0;
  while (fieldIndex < 6) {
    int comma = payload.indexOf(',', start);
    if (comma < 0) {
      fields[fieldIndex++] = payload.substring(start);
      break;
    }
    fields[fieldIndex++] = payload.substring(start, comma);
    start = comma + 1;
  }

  if (fieldIndex < 5) return fix;

  fields[0].trim();
  fields[3].trim();
  fields[4].trim();
  if (fields[0] != "1" || fields[3].length() == 0 || fields[4].length() == 0) return fix;

  float lat = fields[3].toFloat();
  float lon = fields[4].toFloat();
  if (lat < -90.0f || lat > 90.0f || lon < -180.0f || lon > 180.0f) return fix;

  fix.ok = true;
  fix.lat = lat;
  fix.lon = lon;
  return fix;
}

void updateLteStatus(bool verbose = false) {
  String at = sendLteCommand("AT", 1500);
  lteStatus.atOk = at.indexOf("OK") >= 0;

  if (!lteStatus.atOk) {
    lteStatus.simReady = false;
    lteStatus.registered = false;
    lteStatus.attached = false;
    return;
  }

  String cpin = sendLteCommand("AT+CPIN?", 1500);
  String csq = sendLteCommand("AT+CSQ", 1500);
  String cereg = sendLteCommand("AT+CEREG?", 1500);
  String cops = sendLteCommand("AT+COPS?", 3000);
  String cgatt = sendLteCommand("AT+CGATT?", 1500);

  lteStatus.simReady = cpin.indexOf("READY") >= 0;
  lteStatus.csq = parseCsq(csq);
  lteStatus.registered = responseHasRegistration(cereg);
  lteStatus.attached = cgatt.indexOf("+CGATT: 1") >= 0;
  lteStatus.operatorName = cops;

  if (verbose) {
    Serial.printf("[lte-status] at=%u sim=%u reg=%u attach=%u csq=%d\n",
                  lteStatus.atOk, lteStatus.simReady, lteStatus.registered,
                  lteStatus.attached, lteStatus.csq);
  }
}

void configureKoreanCatM() {
  sendLteCommand("AT+CNMP=38", 3000);
  sendLteCommand("AT+CMNB=1", 3000);
  sendLteCommand("AT+CBANDCFG=\"CAT-M\",1,3,5", 3000);
}

void initializeLte() {
  if (!lteSerialStarted) {
    lteSerial.begin(115200, SERIAL_8N1, LTE_RX_PIN, LTE_TX_PIN);
    lteSerialStarted = true;
  }
  delay(1000);
  sendLteCommand("ATE0", 1500);
  sendLteCommand("AT+CMEE=2", 1500);
  configureKoreanCatM();
  sendLteCommand("AT+CEREG=2", 1500);
  sendLteCommand("AT+CGREG=2", 1500);
  sendLteCommand("AT+COPS=0", 10000);
  updateLteStatus(true);
}

void releaseModemPowerKey() {
#if LTE_PWRK_PIN >= 0
  pinMode(LTE_PWRK_PIN, INPUT);
#endif
}

void pulseModemPowerKey(uint16_t lowMs = 1800) {
#if LTE_PWRK_PIN >= 0
  Serial.printf("[pwrk] pulling GPIO%d LOW for %u ms\n", LTE_PWRK_PIN, lowMs);
  pinMode(LTE_PWRK_PIN, OUTPUT);
  digitalWrite(LTE_PWRK_PIN, LOW);
  delay(lowMs);
  releaseModemPowerKey();
  Serial.println("[pwrk] released");
#else
  Serial.println("[pwrk] LTE_PWRK_PIN is disabled");
#endif
}

void pulseModemPowerKeyHigh(uint16_t highMs = 1800) {
#if LTE_PWRK_PIN >= 0
  Serial.printf("[pwrk] driving GPIO%d HIGH for %u ms\n", LTE_PWRK_PIN, highMs);
  pinMode(LTE_PWRK_PIN, OUTPUT);
  digitalWrite(LTE_PWRK_PIN, HIGH);
  delay(highMs);
  releaseModemPowerKey();
  Serial.println("[pwrk] released");
#else
  Serial.println("[pwrk] LTE_PWRK_PIN is disabled");
#endif
}

void powerDownModem() {
  Serial.println("[pwrk] requesting modem power down");
  sendLteCommand("AT+CPOWD=1", 10000);
  lteStatus.atOk = false;
  lteStatus.simReady = false;
  lteStatus.registered = false;
  lteStatus.attached = false;
}

bool probeLteBaud(uint32_t baud) {
  Serial.printf("[lte-probe] trying baud=%lu\n", baud);
  lteSerial.end();
  delay(100);
  lteSerial.begin(baud, SERIAL_8N1, LTE_RX_PIN, LTE_TX_PIN);
  delay(300);

  for (uint8_t i = 0; i < 5; i++) {
    lteSerial.print("AT\r\n");
    String response = readLteResponse(1000);
    Serial.printf("[lte-probe] baud=%lu attempt=%u response=%s\n",
                  baud, i + 1, response.length() ? response.c_str() : "no response");
    if (response.indexOf("OK") >= 0) {
      sendLteCommand("ATE0", 1500);
      return true;
    }
    delay(300);
  }
  return false;
}

void probeLteUart() {
  static const uint32_t baudRates[] = {115200, 9600, 19200, 38400, 57600, 74880, 230400};
  for (uint8_t i = 0; i < sizeof(baudRates) / sizeof(baudRates[0]); i++) {
    if (probeLteBaud(baudRates[i])) {
      Serial.printf("[lte-probe] success baud=%lu\n", baudRates[i]);
      updateLteStatus(true);
      return;
    }
  }

  Serial.println("[lte-probe] no UART response at tested baud rates; restoring 115200");
  lteSerial.end();
  delay(100);
  lteSerial.begin(115200, SERIAL_8N1, LTE_RX_PIN, LTE_TX_PIN);
}

void probeLteLineLevels() {
  lteSerial.end();
  delay(100);

  pinMode(LTE_RX_PIN, INPUT_PULLUP);
  pinMode(LTE_TX_PIN, INPUT_PULLUP);
  delay(20);
  const int rxWithPullup = digitalRead(LTE_RX_PIN);
  const int txWithPullup = digitalRead(LTE_TX_PIN);

  pinMode(LTE_RX_PIN, INPUT_PULLDOWN);
  pinMode(LTE_TX_PIN, INPUT_PULLDOWN);
  delay(20);
  const int rxWithPulldown = digitalRead(LTE_RX_PIN);
  const int txWithPulldown = digitalRead(LTE_TX_PIN);

  pinMode(LTE_RX_PIN, INPUT);
  pinMode(LTE_TX_PIN, INPUT);
  delay(20);

  uint32_t rxHigh = 0;
  uint32_t txHigh = 0;
  uint32_t rxTransitions = 0;
  uint32_t txTransitions = 0;
  int previousRx = digitalRead(LTE_RX_PIN);
  int previousTx = digitalRead(LTE_TX_PIN);

  for (uint32_t i = 0; i < 2000; i++) {
    const int rx = digitalRead(LTE_RX_PIN);
    const int tx = digitalRead(LTE_TX_PIN);
    rxHigh += rx == HIGH;
    txHigh += tx == HIGH;
    rxTransitions += rx != previousRx;
    txTransitions += tx != previousTx;
    previousRx = rx;
    previousTx = tx;
    delayMicroseconds(250);
  }

  Serial.printf(
      "[uart-levels] GPIO%d(ESP_RX/Stamp_TX) high=%lu/2000 transitions=%lu\n",
      LTE_RX_PIN, rxHigh, rxTransitions);
  Serial.printf(
      "[uart-levels] GPIO%d pullup=%d pulldown=%d\n",
      LTE_RX_PIN, rxWithPullup, rxWithPulldown);
  Serial.printf(
      "[uart-levels] GPIO%d(ESP_TX/Stamp_RX) high=%lu/2000 transitions=%lu\n",
      LTE_TX_PIN, txHigh, txTransitions);
  Serial.printf(
      "[uart-levels] GPIO%d pullup=%d pulldown=%d\n",
      LTE_TX_PIN, txWithPullup, txWithPulldown);

  lteSerial.begin(115200, SERIAL_8N1, LTE_RX_PIN, LTE_TX_PIN);
}
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
void loop() {
  pollSerialCommands();
  handleStandaloneTrigger();
  handleBatteryTestTrigger();
  updateSensors();
  updateStateMachine();
  updateBuzzer();
  printStatus();

  if (millis() - lastLteCheckMs >= LTE_CHECK_MS) {
    lastLteCheckMs = millis();
    updateLteStatus(true);
  }
}

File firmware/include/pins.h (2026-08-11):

#pragma once

#ifndef SERIAL_BAUD
#define SERIAL_BAUD 115200
#endif

#ifndef SAMPLE_INTERVAL_MS
#define SAMPLE_INTERVAL_MS 5000
#endif

#ifndef I2C_SDA_PIN
#define I2C_SDA_PIN 21
#endif

#ifndef I2C_SCL_PIN
#define I2C_SCL_PIN 22
#endif

#ifndef LTE_RX_PIN
#define LTE_RX_PIN 16
#endif

#ifndef LTE_TX_PIN
#define LTE_TX_PIN 17
#endif

#ifndef GPS_RX_PIN
#define GPS_RX_PIN -1
#endif

#ifndef GPS_TX_PIN
#define GPS_TX_PIN -1
#endif

#ifndef GPS_BAUD
#define GPS_BAUD 38400
#endif

#ifndef BUZZER_PIN
#define BUZZER_PIN 25
#endif

#ifndef LTE_PWRK_PIN
#define LTE_PWRK_PIN -1
#endif

#ifndef TEST_TRIGGER_PIN
#define TEST_TRIGGER_PIN -1
#endif

#ifndef BATTERY_TEST_PIN
#define BATTERY_TEST_PIN -1
#endif

#ifndef ENABLE_STATE_BUZZER
#define ENABLE_STATE_BUZZER 1
#endif

#ifndef AUTO_LTE_INIT
#define AUTO_LTE_INIT 0
#endif

#ifndef STANDALONE_ALERT_NUMBER
#define STANDALONE_ALERT_NUMBER "01000000000"
#endif

#ifndef TMP117_ADDR
#define TMP117_ADDR 0x48
#endif

#ifndef MAX30102_ADDR
#define MAX30102_ADDR 0x57
#endif

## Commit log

2026-08-11 Initial project archive
    [260708_max30102_waveform_172832.csv, 260708_max30102_waveform_172955.csv, 260708_max30102_waveform_173314.csv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]
2026-08-11 Update README hero image to latest housing revision
2026-09-13 Add complete development evidence archive
    [260810_plate_level_test.stl]
